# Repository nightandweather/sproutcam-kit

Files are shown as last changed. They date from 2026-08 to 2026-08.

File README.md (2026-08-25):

# SproutCam Build Kit

카메라와 환경 센서로 고가 식물의 발근·순화·성장을 기록하는 스마트 재배 캐비닛 설계 프로젝트입니다.

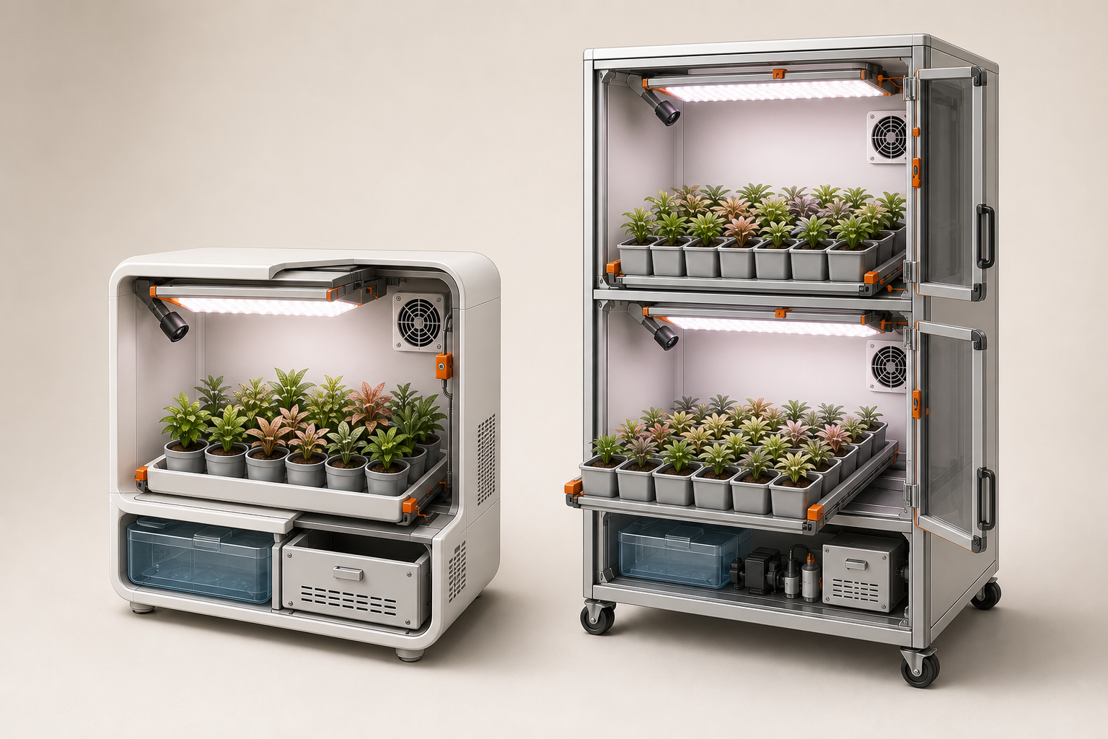
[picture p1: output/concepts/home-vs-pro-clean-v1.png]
HOME 12 and PRO 48 concept


> [!IMPORTANT]
> 이 저장소는 공개 열람이 가능한 설계 프로젝트이지만 오픈소스 또는 오픈 하드웨어로 사용 허가된 저장소가 아닙니다. 별도 서면 허가 없이 설계·코드·문서·이미지를 제품 생산, 판매, 유료 설치, OEM/ODM, 재배포 또는 상업적 파생 제품에 사용할 수 없습니다. 자세한 내용은 [권리 및 상업적 이용 정책](RIGHTS.md)을 확인하십시오.

## 제품군

| 모델 | 구조 | 대상 | 소매 시제품 예산 | 50대 목표 제조원가 |
|---|---:|---|---:|---:|
| HOME 12 | 1구역·12포트 | 개인 수집가·삽수 판매자 | 568,430원 | 399,100원/대 |
| PRO 48 | 2구역·48포트 | 소형 농가·판매점·육묘 작업자 | 1,419,240원 | 971,000원/대 |

금액은 2026-08-25 국내 소매 구매 기준 설계 예산입니다. 공구, 앱·서버 개발, 인증, 금형, 창고와 판매 수수료는 제외합니다.

## 바로 보기

- [HOME 12 + PRO 48 제품 제작서 PDF](output/pdf/SproutCam-HOME12-PRO48-제품제작서-v0.1.pdf)
- [HOME 12 BOM](docs/HOME12_BOM.csv)
- [PRO 48 BOM](docs/PRO48_BOM.csv)
- [프로파일·패널 절단표](docs/HOME_PRO_CUTLIST.csv)
- [이 사업을 계속할지 판단하는 현실 점검](docs/BUSINESS_REALITY_CHECK.md)
- [HOME/PRO 고정구 CAD 생성기](cad/generate_home_pro.py)
- [HOME/PRO STL](output/stl/home-pro/)
- [HOME/PRO STEP](output/step/home-pro/)

## 설계 원칙

- 광원은 위, 식물은 아래에 둡니다.
- 병 전파를 줄이기 위해 공용 순환수조 대신 개별 화분과 탈착식 방수 트레이를 사용합니다.
- 캐비닛 전체는 출력하지 않습니다. 구조는 알루미늄 프로파일·판재·시판 트레이로 만들고, LED 클립·카메라 브래킷·센서 가드·케이블 클립·트레이 스토퍼만 PETG로 출력합니다.
- 제품은 광주기, 습도, 환기, 촬영과 누수 감지를 담당합니다. 냉난방은 실내 설치 환경이 담당합니다.
- 220V 변환은 KC 인증 외장 어댑터에서 끝내고 본체 내부에는 24V/5V DC만 넣습니다.

## HOME 12

- 외형: 560 W x 400 D x 600 H mm
- 2020 알루미늄 프로파일
- 4 x 3 배열의 12개 개별 화분
- 24V 30 W 풀스펙트럼 LED 바 2개
- XIAO ESP32-S3 Sense 카메라 1개
- SHT40, 팬 2개, 분리형 초음파 가습수조, 누수 센서
- KC 24V 5A 120 W 외장 어댑터

## PRO 48

- 외형: 680 W x 560 D x 1700 H mm
- 3030 알루미늄 프로파일과 브레이크 캐스터
- 24포트 독립 구역 2개
- 구역당 24V 40 W 풀스펙트럼 LED 바 2개
- 구역당 카메라·센서·팬·가습수조·제어기 1세트
- 구역당 KC 24V 150 W 이상 외장 어댑터
- 사용 중 상단을 벽체 또는 고정 구조물에 연결

## 제작 순서

1. BOM에서 트레이, 화분, LED와 프로파일을 먼저 구매합니다.
2. 실물 외경과 LED 단면을 측정합니다.
3. 절단표로 프로파일과 패널을 주문합니다.
4. `cad/generate_home_pro.py`의 치수를 확인하고 STL/STEP을 생성합니다.
5. 케이블 클립 한 개를 시험 출력해 프로파일 공차를 확인합니다.
6. 제작서 순서대로 건식 조립합니다.
7. 전자부품을 넣기 전에 24시간 누수 시험을 합니다.
8. 배선 후 누수 차단, 저수위 차단, 4시간 열 시험과 정전 복구 시험을 수행합니다.

CadQuery 실행 예시:

```bash
python3 -m venv .venv
source .venv/bin/activate
pip install cadquery
python cad/generate_home_pro.py
```

PDF 재생성 예시:

```bash
pip install reportlab
python tools/build_home_pro_manual.py
```

## SproutCam One v0.1

저장소에는 앞서 만든 2포트 탁상형 수경재배 실험기도 함께 들어 있습니다.

- [2포트 조립설명서 PDF](output/pdf/SproutCam-One-조립설명서.pdf)
- [기존 BOM](docs/BOM.csv)
- [기존 조립 안내](docs/ASSEMBLY.md)
- [기존 배선 안내](docs/WIRING.md)
- [기존 펌웨어](firmware/)

## 안전 및 판매 전 검토

이 저장소는 개발 시제품용입니다. 실제 판매 전에는 전파·전기·재료·내구·표시 의무에 대해 시험기관과 별도 검토가 필요합니다. 누전차단기가 있는 콘센트를 사용하고, 젖은 구역과 전자함을 분리하며, PRO 48에는 전도 방지 고정을 반드시 적용하십시오.

## 사업성에 관한 입장

이 설계가 기술적으로 가능하다는 사실과 시장에서 팔린다는 사실은 다릅니다. 일반 가정의 채소 자급용 제품으로는 경제성이 약하다는 반론을 포함해, 가능한 고객과 중단 기준을 [사업성 현실 점검](docs/BUSINESS_REALITY_CHECK.md)에 기록했습니다.

## 상업적 협업

다음과 같은 유료 협업을 검토합니다.

- 앱·펌웨어·카메라 기반 생육 분석 연동
- 소규모 재배 실증과 맞춤형 시제품 개발
- 키트 제작, 제조 이관, OEM/ODM 검토
- 설계와 소프트웨어의 상업적 라이선스

상업적 이용 또는 협업 문의는 [새 이슈](https://github.com/nightandweather/sproutcam-kit/issues/new)를 통해 먼저 연락해 주십시오. 이슈는 공개되므로 예산, 계약서, 기술 비밀과 개인정보는 작성하지 마십시오.

## 프로젝트 후원

이 프로젝트의 공개 문서, 실험 기록과 후속 시제품 개발을 후원하려면 [GitHub Sponsors](https://github.com/sponsors/nightandweather)를 이용할 수 있습니다. 후원은 상업적 사용권을 부여하지 않습니다.

## 권리

Copyright © 2026 Lee Kang Houn. All rights reserved.

이 저장소에 별도 라이선스가 명시되지 않은 한 모든 권리는 저작권자에게 유보됩니다. 공개 저장소라는 사실이나 GitHub에서 포크할 수 있다는 사실만으로 제조·판매·재배포 또는 파생 저작물 작성 권한이 부여되지는 않습니다. 전체 정책은 [RIGHTS.md](RIGHTS.md)를 참조하십시오.

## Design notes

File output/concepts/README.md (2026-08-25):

# Concept images

- `home-vs-pro-clean-v1.png`: current cover and README render. Use the dimensions in the fabrication manual, BOM and cut list.
- `archive/home-vs-pro-early-annotated-v1.png`: early visual exploration. Its printed dimensions were superseded by the engineering layout and must not be used for fabrication.

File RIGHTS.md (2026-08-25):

# Rights and Commercial Use Policy

Copyright © 2026 Lee Kang Houn. All rights reserved.

## Status of this repository

This repository is publicly viewable for evaluation, discussion, education about the project, and potential collaboration. It is **source-available, not open source and not open hardware**. No open-source or open-hardware licence is granted unless a specific file or directory explicitly says otherwise.

GitHub users may view and fork the repository only to the extent provided by GitHub's Terms of Service. Public availability does not grant a licence to reproduce, modify, distribute, manufacture from, sell, rent, install for a fee, sublicense, or otherwise commercially exploit the materials in this repository.

## Rights reserved

Without prior written permission from the copyright holder, you may not:

- manufacture or commission a product from the CAD files, drawings, cut lists, BOMs, firmware, or documentation;
- sell, rent, bundle, install for a fee, or commercially deploy a product based substantially on these materials;
- use the materials for OEM, ODM, white-label, consulting, training, or other paid services;
- redistribute, mirror, repackage, sublicense, or publish modified copies of the materials;
- incorporate the materials into a commercial product or a commercially used derivative work; or
- use the SproutCam name, product names, artwork, or project identity in a way that suggests endorsement or an official product.

Ideas, facts, interfaces, third-party components, and other material that cannot be restricted by applicable law are not made exclusive merely by this notice. Third-party dependencies and referenced products remain subject to their own terms and licences.

## Commercial licences and paid collaboration

Commercial manufacturing, product integration, custom development, pilots, and licensing may be available under a separate written agreement. Start a public [commercial inquiry](https://github.com/nightandweather/sproutcam-kit/issues/new) without including confidential information. Sensitive technical, financial, or contractual details should only be exchanged after a private channel and appropriate terms have been agreed.

A donation or sponsorship does not grant manufacturing, redistribution, trademark, patent, support, warranty, or commercial-use rights.

## Contributions

Do not submit substantial code, CAD, documentation, or other copyrighted contributions unless contribution terms have been agreed in advance. Opening an issue or pull request does not transfer ownership and does not create a commercial licence.

## Future releases

Future community editions, individual files, or directories may be offered under separate licences. Any such licence applies only where it is explicitly identified and does not change the status of the rest of this repository.

## No warranty

The materials are experimental prototypes supplied for review without warranty. They have not been certified for sale, electrical safety, radio compliance, food production, plant health, structural safety, or unattended operation. The copyright holder is not offering installation, maintenance, regulatory, or safety assurance through publication of this repository.

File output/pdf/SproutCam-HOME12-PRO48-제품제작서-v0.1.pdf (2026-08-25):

SPROUTCAM PRODUCT BUILD BOOK / v0.1

# SPROUTCAM

# HOME 12 + PRO 48

### 제품 제작서 / 견적서 / 조립 검사서 v0.1

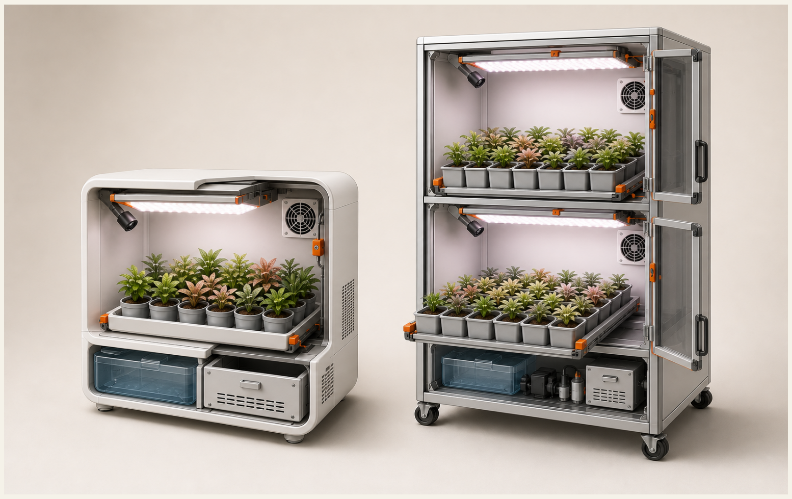
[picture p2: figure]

설계 결론 | 광원은 위, 식물은 아래입니다. 고가 식물의 병 전파를 막기 위해 공용 순환수조 대신 개별 화분과 탈착식 방수 트레이를 사용합니다.
작성 기준일 2026-08-25 | 치수 단위 mm | 금액 VAT 포함 소매 추정

# 0. 먼저 보는 결론

### 직접 한 대를 만드는 예산과 판매용 50대 생산의 제조원가는 다릅니다. 아래 금액은 현재 설계를 실제로 구매 가능한 부품으로

조립하기 위한 기준선입니다.

모델 | 소매 시제품 | 50대 목표 제조원가 | 권장 시험 판매가
HOME 12 | 568,430원 | 399,100원/대 | 799,000-899,000원
PRO 48 | 1,419,240원 | 971,000원/대 | 1,890,000-2,190,000원
원가에 포함 | 본체 구조, 패널, 트레이, 화분, LED, 카메라 제어기, 센서, 팬, 가습, 외장 전원, 소모품, 소매 배송. 50대 목표에는 조립·검사, 포장, 보증충당도 포함.
원가에 제외 | 3D 프린터와 공구, 앱·서버 개발, 금형, KC·EMC·방수 시험, 창고, 반품 물류, 판매 수수료, 마케팅, 부가세 환급 효과.

# 제품 역할 분리

제품이 제어 | 설치 공간이 담당 | 이번 버전에서 제외
광주기·광량 습도·환기 성장 촬영·기록 누수 감지 | 실내 온도 20-28 C 급배수 접근 안정적인 Wi-Fi 주기적 물 보충 | 냉난방 자동 영양액 배합 병해충 완전 진단 판매 등급 자동 판정

### 핵심 판단: HOME은 개인 수집가의 발근·순화·성장 기록 장비이고, PRO는 소형 농가나 식물 판매자의 2구역 생산 장비입니다. 단순

채소 재배기보다 고가 삽수·유묘의 생존률과 기록성을 파는 편이 가격 방어가 쉽습니다.

# 1. 시스템 구조와 안전 경계

### 판매 가능한 제품으로 발전시키려면 처음부터 물과 전원의 경계를 명확히 해야 합니다. 본체 안에는 SELV 저전압 DC만 넣고 220V

변환은 KC 인증 외장 어댑터에서 끝냅니다.

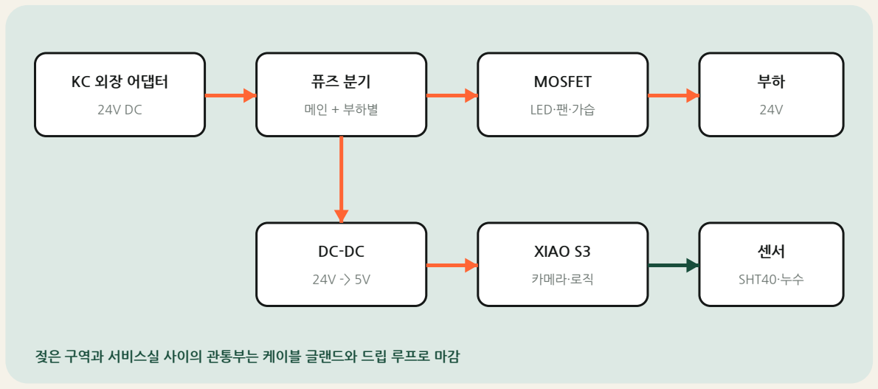
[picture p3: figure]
KC 외장 어댑터; 메인 + 부하별; MOSFET; LED·팬·가습; XIAO S3; 카메라·로직; SHT40·누수; 젖은 구역과 서비스실 사이의 관통부는 케이블 글랜드와 드립 루프로 마감

항목 | 제작 기준 | 불합격 조건
전원 | 외장 24V 어댑터, 본체 입구 퓨즈 | 본체 내부 220V 배선
물 | 트레이·가습수조 독립, 드립 루프 | 전자함 위쪽 호스 연결
전자함 | 서비스실 상단, IP54 이상 목표 | 바닥 최저점에 장착
가습 | 저수위 보호, 최대 연속 15분 | 무수 상태 발진 가능
열 | LED 알루미늄 방열판, 팬 정지 감지 | 30분 후 표면 60 C 초과
소프트웨어 | 로컬 타임아웃 우선 | 클라우드 장애 시 계속 켜짐
작업 전 | 누전차단기가 있는 콘센트를 사용하고, 빈 캐비닛 누수 시험 24시간을 통과하기 전에는 전자부품을 설치하지 않습니다.

# 2. HOME 12 기구 설계

## 외형 560 W x 400 D x 600 H

### 재배 12포트 / 4 x 3

### 식물-LED 250-330 mm

### 서비스실 높이 130 mm

### 트레이 520 x 340 x 50

### 본체 내부는 24V / 5V DC

### 권장 설치: 실내 20-28 C

재료 | 절단 치수 | 수량 | 용도
2020 프로파일 | 560 | 4 | 상·하 폭
2020 프로파일 | 400 | 4 | 상·하 깊이
2020 프로파일 | 600 | 4 | 기둥
2020 프로파일 | 520 | 4 | LED·트레이 레일
2020 프로파일 | 360 | 2 | 서비스 선반
3T 투명 PC | 560x400 / 400x600x2 / 560x600 / 520x450 | 5 | 상·좌우·후면·도어
3T ABS/ACP | 520x360 | 1 | 젖음·건조 분리판

# 배치 기준

### 트레이 바닥은 서비스실 위 148 mm, 화분 상단은 약 235 mm, LED 방열판은 520 mm에 둡니다. 키가 작은 삽수는 LED 레일을 60

mm 아래로 이동합니다. 카메라는 전면 상단 모서리에서 중앙을 향해 30도로 내려다보게 설치합니다.

# 3. HOME 12 구매 목록과 원가

구분 | 시제품 1대 | 50대 목표/대
구조 | 98,000원 | 59,000원
외장 | 106,000원 | 60,000원
재배 | 39,600원 | 20,600원
출력 | 15,000원 | 8,000원
광원 | 68,000원 | 42,000원
제어 | 34,020원 | 21,500원
센서 | 9,900원 | 6,500원
환기 | 18,000원 | 11,000원
가습 | 42,000원 | 25,000원
전원 | 35,910원 | 24,000원
안전 | 13,000원 | 7,500원
기록 | 8,000원 | 5,000원
배선 | 18,000원 | 10,000원
마감 | 18,000원 | 10,000원
물류 | 45,000원 | 0원
양산 | 0원 | 89,000원

# 상세 BOM 1/2

부품 | 규격 | 수량 | 시제품 소계
2020 알루미늄 프로파일 절단 세트 | 560x4, 400x4, 600x4, 520x4, 360x2 mm | 1 | 62,000원
브라켓·T너트·M5 볼트 | 2020용 코너브라켓 24개 포함 | 1 | 36,000원
투명 폴리카보네이트 패널 | 3T 재단 5장 | 1 | 82,000원
도어 하드웨어·실리콘 씰 | 힌지 2·래치 2·손잡이 1 | 1 | 24,000원
탈착식 방수 트레이 | 520x340x50 mm 또는 근사 규격 | 1 | 18,000원
개별 화분 | 상단 75-80 mm·배수형 | 12 | 21,600원
PETG 필라멘트 | 고정구 0.65 kg 예상 | 1 | 15,000원
24V 풀스펙트럼 LED 바 | 30 W·길이 500 mm·방열판 포함 | 2 | 68,000원
XIAO ESP32-S3 Sense | 카메라 포함 | 1 | 25,520원
SHT40 온습도 보드 | I2C·3.3 V | 1 | 9,900원
80 mm 저소음 팬 | 24 V 또는 12 V | 2 | 18,000원
24V 초음파 미스트 모듈 | 저수위 보호형 권장 | 1 | 24,000원

# 3. HOME 12 구매 목록과 원가

# 상세 BOM 2/2

부품 | 규격 | 수량 | 시제품 소계
가습수 탱크·덕트·체크밸브 | 2 L 분리형 | 1 | 18,000원
4채널 MOSFET 보드 | 3.3 V 로직 호환 | 1 | 8,500원
DC-DC 벅 컨버터 | 24 V to 5 V 3 A | 1 | 6,000원
KC 24V 5A 외장 어댑터 | 120 W·접지형 | 1 | 29,910원
인라인 퓨즈·분기 단자 | 메인 5 A·부하별 1-3 A | 1 | 7,000원
누수 센서 | 접점식 또는 로프형 | 1 | 6,000원
microSD 카드 | 32 GB·고내구 권장 | 1 | 8,000원
케이블·JST·글랜드·열수축튜브 | 24/5 V 하네스 1식 | 1 | 18,000원
볼트·방수테이프·실란트 | 1식 | 1 | 18,000원
개별 배송비 합계 | 판매처 통합 전 소매 구매 | 1 | 45,000원
포장재 | 이중 골판지·완충재·설명서 | 1 | 0원
조립·검사 인건비 | 약 2.0시간 | 1 | 0원
초기불량·보증 충당 | 목표 제조원가의 약 5% | 1 | 0원
구매 순서 | 먼저 프로파일·트레이·화분·LED 실물 치수를 확정한 뒤 패널 재단과 3D 출력을 주문합니다. 트레이와 LED를 나중에 바꾸면 고정구를 다시 출력하게 됩니다.

# 4. HOME 12 조립 순서

### 01 하부 사각 프레임과 4개 기둥을 손조임으로 조립합니다. 대각선 길이 차가 2 mm 이내인지 확인한 뒤

체결합니다.

02 높이 130 mm에 서비스 선반 레일을 설치하고 ABS/ACP 분리판 둘레를 중성 실리콘으로 밀봉합니다.

03 트레이 레일과 3D 출력 코너 스토퍼 4개를 설치합니다. 트레이는 앞쪽으로 완전히 빠져야 합니다.

04 상·후·측면 PC 패널을 장착하고 전면 도어 간극 3 mm를 확보합니다. 환기 팬은 후면 상단 배기로 둡니다.

### 05 LED 두 줄을 알루미늄 레일과 출력 클립으로 고정합니다. 방열판과 PC 상판 사이 간격은 20 mm

이상입니다.

### 06 카메라 브래킷, SHT40 가드, 케이블 클립을 장착합니다. 센서는 미스트 직분사와 LED 열원에서 120 mm

이상 떨어뜨립니다.

### 07 가습수조와 덕트를 서비스실 왼쪽, 전자함을 오른쪽에 배치합니다. 모든 호스 연결부는 전자함보다 낮게

둡니다.

### 08 24시간 누수 시험 후 배선하고 5V 레일, 팬 방향, 저수위 차단, 누수 경보, 카메라 화각을 순서대로

검사합니다.

# 5. HOME 12 배선과 전력

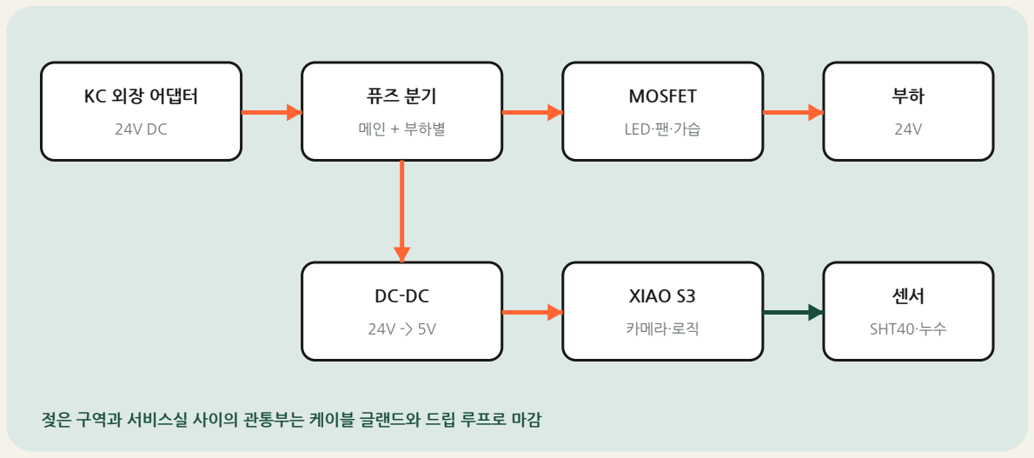
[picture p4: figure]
KC 외장 어댑터; 메인 + 부하별; MOSFET; LED·팬·가습; XIAO S3; 카메라·로직; SHT40·누수; 젖은 구역과 서비스실 사이의 관통부는 케이블 글랜드와 드립 루프로 마감

부하 | 정격 | 예상 최대 | 퓨즈
LED 2개 | 24V | 60 W / 2.5 A | 3 A
미스트 | 24V | 24 W / 1.0 A | 1.5 A
팬 2개 | 24V 또는 12V | 6 W / 0.25 A | 1 A
제어·카메라 | 5V | 5 W / 1.0 A | 벅 입력 1 A
합계 | 24V | 약 95 W / 4.0 A | 메인 5 A
기능 | 연결 | 제어 규칙
SHT40 | I2C SDA/SCL | 30초 평균, 결로 방지
LED | MOSFET CH1 | 기본 12시간, PWM 선택
배기 팬 | MOSFET CH2 | 습도 상한 또는 주기 환기
미스트 | MOSFET CH3 | 최대 15분, 5분 휴지
누수 | 디지털 입력 | 감지 즉시 모든 부하 OFF

HOME 피크 부하는 95 W이므로 24V 5A 120 W 어댑터에 약 20% 여유가 남습니다. LED나 미스트 모듈을 상향하면 어댑터와 메인 퓨즈를 다시 계산해야 합니다.

# 6. PRO 48 기구 설계

## 외형 680 W x 560 D x 1700 H

### 2개 독립 구역 x 24포트

### 구역별 LED 80 W

### 구역별 카메라·센서·가습

### 트레이 610 x 470 x 40

### 서비스실 높이 280 mm

### 구역당 24V 150 W 어댑터

### 브레이크 캐스터 4개

재료 | 절단 치수 | 수량 | 용도
3030 프로파일 | 1700 | 4 | 기둥
3030 프로파일 | 680 | 8 | 상·하·구역 폭
3030 프로파일 | 560 | 12 | 상·하·구역 깊이
4T 투명 PC | 680x560 / 560x1700x2 / 680x1700 | 4 | 상·좌우·후면
4T 투명 PC | 640x600x2 / 640x250 | 3 | 구역·서비스 도어
4T ABS/ACP | 620x500 | 3 | 구역 바닥·분리판
독립 2구역 | ZONE A와 B는 어댑터, 제어기, 센서, 팬, 가습수조를 따로 둡니다. 한 구역 고장이나 병 발생이 다른 구역으로 번지는 것을 줄이고 서로 다른 순화 레시피를 운전할 수 있습니다.

# 7. PRO 48 구매 목록과 원가

구분 | 시제품 1대 | 50대 목표/대
구조 | 295,000원 | 175,000원
외장 | 252,000원 | 143,000원
재배 | 135,600원 | 70,000원
출력 | 28,000원 | 15,000원
광원 | 176,000원 | 108,000원
제어 | 68,040원 | 43,000원
센서 | 19,800원 | 13,000원
환기 | 48,000원 | 30,000원
가습 | 102,000원 | 60,000원
전원 | 91,800원 | 62,000원
안전 | 26,000원 | 15,000원
기록 | 16,000원 | 10,000원
배선 | 35,000원 | 21,000원
마감 | 36,000원 | 21,000원
물류 | 90,000원 | 0원
양산 | 0원 | 185,000원

# 상세 BOM 1/2

부품 | 규격 | 수량 | 시제품 소계
3030 알루미늄 프로파일 절단 세트 | 1700x4, 680x8, 560x12 mm | 1 | 210,000원
브라켓·T너트·M6 볼트 | 3030용 보강 브라켓 48개 포함 | 1 | 85,000원
투명 폴리카보네이트 패널 | 4T 재단·도어 포함 | 1 | 210,000원
도어 하드웨어·자석 씰 | 힌지 6·래치 6·손잡이 3 | 1 | 42,000원
탈착식 방수 트레이 | 610x470x40 mm | 2 | 78,000원
개별 화분 | 상단 75-80 mm·배수형 | 48 | 57,600원
PETG 필라멘트 | 고정구 1.4 kg 예상 | 1 | 28,000원
24V 풀스펙트럼 LED 바 | 40 W·길이 600 mm·방열판 포함 | 4 | 176,000원
XIAO ESP32-S3 Sense | 구역별 카메라 포함 | 2 | 51,040원
SHT40 온습도 보드 | I2C·3.3 V | 2 | 19,800원
120 mm 저소음 팬 | 24 V 또는 12 V | 4 | 48,000원
24V 초음파 미스트 모듈 | 구역별·저수위 보호형 | 2 | 56,000원

# 7. PRO 48 구매 목록과 원가

# 상세 BOM 2/2

부품 | 규격 | 수량 | 시제품 소계
가습수 탱크·덕트·체크밸브 | 구역별 3 L 분리형 | 2 | 46,000원
4채널 MOSFET 보드 | 3.3 V 로직 호환 | 2 | 17,000원
DC-DC 벅 컨버터 | 24 V to 5 V 3 A | 2 | 12,000원
KC 24V 6.25A 이상 외장 어댑터 | 구역별 150 W 이상·접지형 | 2 | 79,800원
인라인 퓨즈·분기 단자 | 구역별 메인 5 A·부하별 1-3 A | 2 | 14,000원
누수 센서 | 구역별 접점식 또는 로프형 | 2 | 12,000원
microSD 카드 | 32 GB·고내구 권장 | 2 | 16,000원
케이블·JST·글랜드·열수축튜브 | 2구역 하네스 1식 | 1 | 35,000원
캐스터·볼트·실란트·받침판 | 브레이크 캐스터 4개 포함 | 1 | 36,000원
개별 배송·화물비 합계 | 판매처 통합 전 소매 구매 | 1 | 90,000원
포장재 | 이중 골판지·모서리 보강·설명서 | 1 | 0원
조립·검사 인건비 | 약 4.0시간 | 1 | 0원
초기불량·보증 충당 | 목표 제조원가의 약 5% | 1 | 0원

### 큰 원가 3개

### 외장·프레임 약 54.7만원, 광원 17.6만원, 배송·조립 준비 약 9만원이 시제품 가격을 끌어올립니다. 실제 양산에서는 패널 네스팅과 프로파일 일괄 절단이 가장 먼저 절감할

부분입니다.

# 8. PRO 48 조립 순서

### 01 캐스터가 달린 하부 3030 프레임을 조립하고 수평계를 사용합니다. 두 대각선 차이는 3 mm 이내로

맞춥니다.

02 기둥 4개와 상부 프레임을 세운 뒤 벽 고정용 전도 방지 스트랩 위치를 확보합니다.

03 높이 280, 930, 1610 mm에 구역 레일을 설치하고 ABS/ACP 분리판 둘레를 실링합니다.

### 04 각 구역 트레이 레일과 스토퍼를 설치합니다. 24개 화분을 넣은 상태에서도 한 손으로 트레이가 빠져야

합니다.

05 구역당 LED 2줄, 배기 팬 2개, 카메라 1개, SHT40 1개를 설치합니다. 두 구역의 하네스 색을 다르게 합니다.

### 06 서비스실을 좌측 가습수조 A/B, 중앙 전원 입구, 우측 전자함 A/B로 구획합니다. 물통은 별도 누수받이에

둡니다.

07 패널과 도어를 설치하고 각 구역의 문을 닫았을 때 2-5 mm 흡기 간극을 남깁니다.

08 구역별 24시간 누수 시험, 4시간 열 시험, 정전 복구, 네트워크 단절, 누수 센서 강제 작동 시험을 합니다.

# 9. PRO 48 배선과 전력

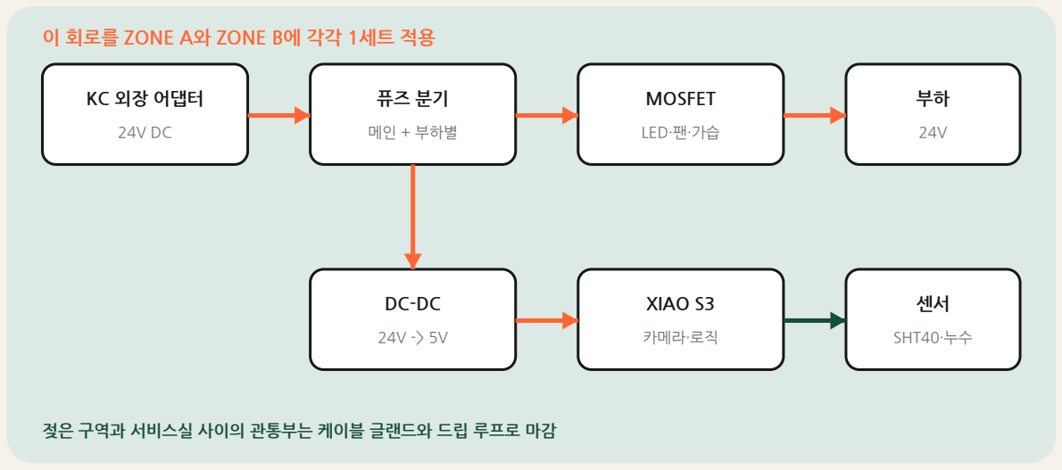
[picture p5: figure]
KC 외장 어댑터; 메인 + 부하별; MOSFET; LED·팬·가습; XIAO S3; 카메라·로직; SHT40·누수; 젖은 구역과 서비스실 사이의 관통부는 케이블 글랜드와 드립 루프로 마감; 이 회로를 ZONE A와 ZONE B에 각각 1세트 적용

구역당 부하 | 정격 | 예상 최대 | 퓨즈
LED 2개 | 24V | 80 W / 3.33 A | 4 A
미스트 | 24V | 24 W / 1.0 A | 1.5 A
팬 2개 | 24V 또는 12V | 10 W / 0.42 A | 1 A
제어·카메라 | 5V | 5 W / 1.0 A | 벅 입력 1 A
합계 | 24V | 약 119 W / 5.0 A | 메인 6.3 A

### 구역마다 24V 150 W 이상 외장 어댑터를 사용합니다. 120 W 어댑터는 정격과 피크가 너무 가까워 제외했습니다. 두 구역의 DC

음극을 합치지 않아도 되며, 통신은 Wi-Fi로 묶는 편이 고장 격리에 유리합니다.

전도 방지 | PRO 48은 높이 1700 mm입니다. 브레이크 캐스터만으로는 부족하므로 사용 중에는 상단을 벽체 또는 고정 구조물에 스트랩으로 연결하십시오.

# 10. 3D 출력 고정구

### 캐비닛 전체를 출력하지 않습니다. 크고 물을 받는 부품은 프로파일·판재·시판 트레이로 만들고, 치수 적응이 필요한 작은 고정구만

PETG로 출력합니다.

파일 | HOME | PRO | 권장 수량 | 역할
led_clip_2020 / 3030 | 2020 | 3030 | 8 / 16 | LED 레일 고정
camera_bracket_*_30deg | 2020 | 3030 | 1 / 2 | 카메라 30도 설치
sht40_sensor_guard | 공용 | 공용 | 1 / 2 | 센서 비말 보호
cable_clip_2020 / 3030 | 2020 | 3030 | 12 / 24 | 하네스 정리
tray_corner_2020 / 3030 | 2020 | 3030 | 4 / 8 | 트레이 위치 반복
설정 | 권장값 | 이유
재료 | PETG | 습기·열에 PLA보다 안정
노즐/레이어 | 0.4 / 0.20 mm | 치수와 시간 균형
벽/상하단 | 4줄 / 5레이어 | 클립 파손 억제
인필 | 30% gyroid | 충격 방향 분산
공차 | 프로파일 +0.8 mm | 프린터 편차 흡수
볼트 | M4 관통 + T너트 | 스냅만으로 하중 지지 금지

STL은 output/stl/home-pro, 수정 가능한 STEP은 output/step/home-pro에 생성됩니다. 첫 출력은 케이블 클립 1개로 프로파일 맞춤을 확인한 후 진행합니다.

# 11. 완성품 검사와 최초 가동

시험 | 방법 | 합격 기준
프레임 | 대각선·수평·도어 반복 | 흔들림 없음, 간극 일정
누수 | 트레이·가습수조 만수 24시간 | 바닥·관통부 물방울 0
절연 경계 | 어댑터 분리 후 내부 확인 | 220V 부품 0개
5V 레일 | 카메라 스트리밍 중 측정 | 4.85-5.15V
열 | 모든 부하 4시간 | LED 60 C 이하, 커넥터 변색 0
누수 차단 | 센서에 물 3 ml | 5초 안에 모든 부하 OFF
저수위 | 가습수조 비우기 | 미스트 기동 거부
통신 장애 | Wi-Fi 30분 차단 | 예약·안전 타임아웃 유지
정전 복구 | 전원 5회 반복 | 미스트 OFF로 안전 부팅
카메라 | 빈칸 없이 전체 포트 확인 | HOME 12 / PRO 각 24포트 식별

# 가동 레시피 초안

단계 | 기간 | 습도 | 광주기 | 환기
발근 | 1-7일 | 85-92% | 12h / 약광 | 10분마다 1분
순화 | 8-14일 | 하루 3%p 감소 | 12-14h | 5분마다 1분
성장 | 15일 이후 | 60-75% | 14h | 습도 상한 연동

식물 종과 기질에 따라 레시피 검증이 필요합니다. 고습 환경은 곰팡이 위험을 키우므로 상대습도만이 아니라 잎 표면 결로와 공기 흐름을 함께 관찰하십시오.

# 12. 원가를 판매가로 바꾸는 법

항목 | HOME 12 | PRO 48
시제품 BOM | 568,430원 | 1,419,240원
50대 목표 제조원가 | 399,100원 | 971,000원
시험 판매가 | 799,000-899,000원 | 1,890,000-2,190,000원
원가율 | 44-50% | 44-51%
예상 월 전력 | 약 30-45 kWh | 약 80-120 kWh
주요 고객 | 고가 관엽 수집가·삽수 판매자 | 소형 농가·판매점·육묘 작업자

# 사업성 검증 순서

1 | HOME 12 한 대를 먼저 만들고 30일 순화 로그를 공개합니다.
2 | 고가 식물 12개 중 생존률, 작업시간, 사진 기록 가치를 측정합니다.
3 | 예약금 10만원을 받는 유료 선주문 10건이 생기기 전에는 PRO 금형을 만들지 않습니다.
4 | 첫 10대는 프로파일 조립품으로 판매해 고장 데이터를 모읍니다.
5 | 50대 주문이 보이면 패널 네스팅, 하네스 외주, 판금 서비스실부터 양산화합니다.

### 돈이 되는 조건

### 기계 자체보다 '고가 삽수 12개를 한 번에 순화하면서 실패 원인을 사진과 환경 로그로 남긴다'는 결과를 팔아야 합니다. 월 구독은 원격 알림, 타임랩스 보관, 재배 레시피 공유가

실제로 반복 사용될 때만 붙입니다.

# 13. 가격 근거와 제작 전 확인

### 가격은 2026-08-25 국내 소매 구매를 가정한 예산입니다. 판매처·절단비·배송지에 따라 달라질 수 있으며, 특정 판매자의 공식 견적이

아닌 시장가 기반 설계 예산입니다.

항목 | 확인값 | 근거
XIAO ESP32-S3 Sense | VAT 포함 25,520원 | 디바이스마트 상품 페이지
24V 5A 어댑터 | 약 29,910원부터 | 다나와 24V 5A 검색 결과
2020 프로파일 | 200-800 mm 소매 비교가 존재 | 다나와 2020 프로파일 비교
나머지 부품 | 샘플 구매 예산 | 국내 쇼핑몰 1-3개 견적 후 확정

# 원문 링크

XIAO: https://www.devicemart.co.kr/goods/view?no=14991199

24V 5A 어댑터: https://search.danawa.com/mobile/dsearch.php?keyword=24v+5a+adapter

2020 프로파일: https://prod.danawa.com/info/?pcode=20334098

제작 전 실측 | 확인
구매 트레이 외경과 레일 간격 | □
화분 상단 외경과 4x3 / 6x4 피치 | □
LED 실제 길이·폭·발열·입력전압 | □
어댑터 KC 인증번호와 출력 커넥터 | □
팬 방향·전압과 최대 전류 | □
미스트 모듈 저수위 보호 동작 | □
패널 도어 간극과 힌지 홀 위치 | □
벽체 전도 방지 고정점(PRO) | □

본 문서는 개발 시제품 제작서입니다. 실제 판매 전에는 전파·전기·재료·내구·표시 의무에 대해 시험기관과 별도로 검토해야 합니다.

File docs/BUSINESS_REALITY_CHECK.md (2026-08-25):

# SproutCam 사업성 현실 점검

작성일: 2026-08-25

## 현재 결론

**일반 가정용 스마트팜으로는 사업성이 약하다. 고가 삽수·유묘를 반복 취급하는 판매자와 수집가를 위한 소형 순화 장비라면 제한적으로 검증할 가치가 있다.**

이 문서는 제품을 정당화하기 위한 자료가 아니다. 설계를 실제 제품으로 만들기 전에 왜 실패할 수 있는지 기록하고, 중단할 조건을 미리 정하기 위한 문서다.

## 대중제품이 되기 어려운 이유

1. **채소 가격을 이기기 어렵다.** 기계, 전기, 씨앗, 영양제, 청소와 실패 비용을 합치면 마트에서 채소를 사는 것보다 비싸다.
2. **자급자족 장비가 아니다.** HOME 12나 PRO 48의 재배 면적으로 가정의 식량 수요를 감당할 수 없다.
3. **관리가 사라지지 않는다.** 물 보충, 세척, 솎기, 곰팡이와 해충 관리는 자동화 이후에도 남는다.
4. **집 안 공간을 오래 점유한다.** 작은 수확량에 비해 캐비닛의 부피와 소음, 빛 공해가 크다.
5. **대기업의 존재가 시장성을 증명하지 않는다.** LG 틔운 미니는 2022년 사전판매 1,000대가 6일 만에 판매됐지만, 이후 전체 틔운 시리즈의 누적 판매량은 공개되지 않았다. 공개된 확실한 초기 판매 숫자와 지속적인 대량 수요는 구분해야 한다.

참고:

- LG 공식 사전판매 자료: https://www.lg.co.kr/media/release/24551
- 현재 LG 틔운 제품군: https://www.lge.co.kr/category/lg-tiiun
- 2023년 틔운 키트 확장 자료: https://www.lg.co.kr/media/release/27049

## 구매 이유가 성립할 수 있는 고객

| 고객 | 구매 이유 | 위험 |
|---|---|---|
| 희귀 관엽 수집가 | 비싼 삽수의 발근·순화 실패 감소 | 고객 수가 적고 가격 민감도가 불명확 |
| 삽수·유묘 개인 판매자 | 반복 작업 표준화와 성장 기록 | 판매 규모가 작으면 장비 회수 불가 |
| 소형 육묘 사업자 | 두 구역의 독립 레시피와 이력 관리 | 기존 온실 설비가 더 저렴할 수 있음 |
| 교육·전시 공간 | 관찰, 타임랩스, 체험 콘텐츠 | 일회성 예산에 의존 |

일반 소비자에게 `집에서 채소를 키우는 가전`으로 판매하지 않는다. 제품이 보호하는 식물의 가치가 장비 가격보다 충분히 높아야 한다.

## 경제성이 생기는 경계

PRO 48의 시험 판매가를 189만-219만원으로 가정한다.

### 경제성이 약한 사례

- 48칸 모두 사용
- 식물 한 개의 순이익 2만원
- 한 사이클 총 잠재 순이익 96만원
- 장비가 생존률을 20%p 높여도 추가 이익은 약 19.2만원

여러 사이클과 작업시간 절감까지 고려해야 장비를 회수할 수 있다. 이 고객에게는 판매가 어렵다.

### 경제성이 가능한 사례

- 48칸 모두 사용
- 식물 한 개의 순이익 10만원
- 생존률이 70%에서 90%로 개선
- 한 사이클 추가 이익 약 96만원

이 경우에는 2-3회 사이클 안에 장비 가격을 회수할 가능성이 생긴다. 따라서 핵심 변수는 재배 수량보다 **식물 한 개의 이익과 실제 생존률 개선 폭**이다.

## 제품명과 포지셔닝 수정안

- `HOME 12` -> `PROP 12`: 개인용 가전보다 12포트 발근·순화 장비
- `PRO 48` -> `NURSERY 48`: 2구역 48포트 소형 육묘 장비

핵심 문구는 `식물을 대신 키워준다`가 아니라 다음에 가깝다.

> 고가 삽수를 한 번에 순화하고, 실패 원인을 사진과 환경 로그로 남기는 장비.

## 제작 전에 실행할 검증

1. 현재 렌더, 제작서와 예상 가격으로 공개 제품 페이지를 만든다.
2. PROP 12는 79만-89만원, NURSERY 48은 189만-219만원을 숨기지 않고 표시한다.
3. 단순 이메일 수집이 아니라 10만원의 환불 가능한 예약금을 받는 조건을 제시한다.
4. 유료 예약 10건이 모이기 전에는 PRO 외장 금형이나 대량 부품을 발주하지 않는다.
5. 예약 고객에게 약속할 수 있는 첫 제품은 프로파일 조립식 소량 생산품으로 제한한다.
6. 30일 순화 실험에서 생존률, 작업시간, 전력, 결로, 곰팡이와 센서 오류를 공개한다.

## 중단 기준

다음 중 하나라도 충족되면 소비자 완제품 사업을 중단하거나 설계 공개 프로젝트로 남긴다.

- 목표 가격을 공개한 뒤 60일 안에 유료 예약 10건을 확보하지 못함
- 30일 시험에서 대조군 대비 생존률 개선이 10%p 미만
- HOME 제조원가가 40만원 아래로 내려가지 않음
- PRO 제조원가가 100만원 아래로 내려가지 않음
- 청소와 물 관리 시간이 주당 30분 이상 필요함
- 결로·곰팡이·누수 문제를 사용자가 분해하지 않고 해결할 수 없음
- 카메라 기록이 실제 구매 이유가 아니라 단순 구경거리로만 평가됨

## 계속할 조건

- 고객이 이미 한 개당 수만-수십만원의 식물을 반복 취급함
- 장비가 없는 현재 방식에서 손실액을 측정할 수 있음
- 순화 레시피와 사진 이력이 판매 신뢰도 또는 단가를 높임
- 소모품 강매 없이도 하드웨어와 서비스의 가격이 성립함
- 한 명의 전문 작업자가 여러 대를 관리할 수 있음

## 현재 판단의 신뢰도

- 기술적 제작 가능성: 높음
- 일반 가정용 대중시장 가능성: 낮음
- 희귀식물 수집가 시장 가능성: 낮음-중간
- 소형 판매자용 순화 장비 가능성: 중간, 유료 예약으로 확인 필요
- 프랜차이즈형 대규모 확장 가능성: 아직 판단 불가

이 프로젝트의 다음 단계는 더 정교한 렌더나 더 많은 기능이 아니다. **정해진 가격으로 실제 예약금을 내는 사람이 있는지 확인하는 것**이다.

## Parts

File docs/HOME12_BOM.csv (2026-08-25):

category | item | specification | qty | prototype_unit_krw | prototype_subtotal_krw | target_50unit_subtotal_krw | source_or_basis
구조 | 2020 알루미늄 프로파일 절단 세트 | 560x4, 400x4, 600x4, 520x4, 360x2 mm | 1 | 62000 | 62000 | 38000 | 국내 소매 절단·배송 포함 견적
구조 | 브라켓·T너트·M5 볼트 | 2020용 코너브라켓 24개 포함 | 1 | 36000 | 36000 | 21000 | 국내 소매 견적
외장 | 투명 폴리카보네이트 패널 | 3T 재단 5장 | 1 | 82000 | 82000 | 46000 | 국내 판재 재단 견적
외장 | 도어 하드웨어·실리콘 씰 | 힌지 2·래치 2·손잡이 1 | 1 | 24000 | 24000 | 14000 | 국내 소매 견적
재배 | 탈착식 방수 트레이 | 520x340x50 mm 또는 근사 규격 | 1 | 18000 | 18000 | 11000 | 시판 PP/ABS 트레이
재배 | 개별 화분 | 상단 75-80 mm·배수형 | 12 | 1800 | 21600 | 9600 | 12개 묶음 단가
출력 | PETG 필라멘트 | 고정구 0.65 kg 예상 | 1 | 15000 | 15000 | 8000 | 1 kg 롤 안분
광원 | 24V 풀스펙트럼 LED 바 | 30 W·길이 500 mm·방열판 포함 | 2 | 34000 | 68000 | 42000 | 샘플 구매 예산
제어 | XIAO ESP32-S3 Sense | 카메라 포함 | 1 | 25520 | 25520 | 17000 | https://www.devicemart.co.kr/goods/view?no=14991199
센서 | SHT40 온습도 보드 | I2C·3.3 V | 1 | 9900 | 9900 | 6500 | 국내 모듈 소매 추정
환기 | 80 mm 저소음 팬 | 24 V 또는 12 V | 2 | 9000 | 18000 | 11000 | 국내 소매 추정
가습 | 24V 초음파 미스트 모듈 | 저수위 보호형 권장 | 1 | 24000 | 24000 | 14000 | 국내 소매 추정
가습 | 가습수 탱크·덕트·체크밸브 | 2 L 분리형 | 1 | 18000 | 18000 | 11000 | 시판 용기 조합
제어 | 4채널 MOSFET 보드 | 3.3 V 로직 호환 | 1 | 8500 | 8500 | 4500 | 국내 모듈 소매 추정
전원 | DC-DC 벅 컨버터 | 24 V to 5 V 3 A | 1 | 6000 | 6000 | 3000 | 국내 모듈 소매 추정
전원 | KC 24V 5A 외장 어댑터 | 120 W·접지형 | 1 | 29910 | 29910 | 21000 | https://search.danawa.com/mobile/dsearch.php?keyword=24v+5a+adapter
안전 | 인라인 퓨즈·분기 단자 | 메인 5 A·부하별 1-3 A | 1 | 7000 | 7000 | 4000 | 국내 전장 소매 추정
안전 | 누수 센서 | 접점식 또는 로프형 | 1 | 6000 | 6000 | 3500 | 국내 모듈 소매 추정
기록 | microSD 카드 | 32 GB·고내구 권장 | 1 | 8000 | 8000 | 5000 | 국내 소매 추정
배선 | 케이블·JST·글랜드·열수축튜브 | 24/5 V 하네스 1식 | 1 | 18000 | 18000 | 10000 | 소모품 안분
마감 | 볼트·방수테이프·실란트 | 1식 | 1 | 18000 | 18000 | 10000 | 소모품 안분
물류 | 개별 배송비 합계 | 판매처 통합 전 소매 구매 | 1 | 45000 | 45000 | 0 | 구매처 수에 따른 예산
양산 | 포장재 | 이중 골판지·완충재·설명서 | 1 | 0 | 0 | 24000 | 50대 기준 목표
양산 | 조립·검사 인건비 | 약 2.0시간 | 1 | 0 | 0 | 45000 | 50대 기준 목표
양산 | 초기불량·보증 충당 | 목표 제조원가의 약 5% | 1 | 0 | 0 | 20000 | 50대 기준 목표
TOTAL | 총계 |  | 1 |  | 568430 | 399100 | 도구·인증·금형·부가세 환급·개발비 제외

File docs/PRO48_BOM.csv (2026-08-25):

category | item | specification | qty | prototype_unit_krw | prototype_subtotal_krw | target_50unit_subtotal_krw | source_or_basis
구조 | 3030 알루미늄 프로파일 절단 세트 | 1700x4, 680x8, 560x12 mm | 1 | 210000 | 210000 | 125000 | 국내 소매 절단·화물 포함 견적
구조 | 브라켓·T너트·M6 볼트 | 3030용 보강 브라켓 48개 포함 | 1 | 85000 | 85000 | 50000 | 국내 소매 견적
외장 | 투명 폴리카보네이트 패널 | 4T 재단·도어 포함 | 1 | 210000 | 210000 | 118000 | 국내 판재 재단 견적
외장 | 도어 하드웨어·자석 씰 | 힌지 6·래치 6·손잡이 3 | 1 | 42000 | 42000 | 25000 | 국내 소매 견적
재배 | 탈착식 방수 트레이 | 610x470x40 mm | 2 | 39000 | 78000 | 44000 | 주문 절곡 PP/ABS 목표
재배 | 개별 화분 | 상단 75-80 mm·배수형 | 48 | 1200 | 57600 | 26000 | 48개 묶음 단가
출력 | PETG 필라멘트 | 고정구 1.4 kg 예상 | 1 | 28000 | 28000 | 15000 | 2 kg 구매 안분
광원 | 24V 풀스펙트럼 LED 바 | 40 W·길이 600 mm·방열판 포함 | 4 | 44000 | 176000 | 108000 | 샘플 구매 예산
제어 | XIAO ESP32-S3 Sense | 구역별 카메라 포함 | 2 | 25520 | 51040 | 34000 | https://www.devicemart.co.kr/goods/view?no=14991199
센서 | SHT40 온습도 보드 | I2C·3.3 V | 2 | 9900 | 19800 | 13000 | 국내 모듈 소매 추정
환기 | 120 mm 저소음 팬 | 24 V 또는 12 V | 4 | 12000 | 48000 | 30000 | 국내 소매 추정
가습 | 24V 초음파 미스트 모듈 | 구역별·저수위 보호형 | 2 | 28000 | 56000 | 34000 | 국내 소매 추정
가습 | 가습수 탱크·덕트·체크밸브 | 구역별 3 L 분리형 | 2 | 23000 | 46000 | 26000 | 시판 용기 조합
제어 | 4채널 MOSFET 보드 | 3.3 V 로직 호환 | 2 | 8500 | 17000 | 9000 | 국내 모듈 소매 추정
전원 | DC-DC 벅 컨버터 | 24 V to 5 V 3 A | 2 | 6000 | 12000 | 6000 | 국내 모듈 소매 추정
전원 | KC 24V 6.25A 이상 외장 어댑터 | 구역별 150 W 이상·접지형 | 2 | 39900 | 79800 | 56000 | 24V 150W KC 완제품 견적 필요
안전 | 인라인 퓨즈·분기 단자 | 구역별 메인 5 A·부하별 1-3 A | 2 | 7000 | 14000 | 8000 | 국내 전장 소매 추정
안전 | 누수 센서 | 구역별 접점식 또는 로프형 | 2 | 6000 | 12000 | 7000 | 국내 모듈 소매 추정
기록 | microSD 카드 | 32 GB·고내구 권장 | 2 | 8000 | 16000 | 10000 | 국내 소매 추정
배선 | 케이블·JST·글랜드·열수축튜브 | 2구역 하네스 1식 | 1 | 35000 | 35000 | 21000 | 소모품 안분
마감 | 캐스터·볼트·실란트·받침판 | 브레이크 캐스터 4개 포함 | 1 | 36000 | 36000 | 21000 | 국내 소매 추정
물류 | 개별 배송·화물비 합계 | 판매처 통합 전 소매 구매 | 1 | 90000 | 90000 | 0 | 구매처 수에 따른 예산
양산 | 포장재 | 이중 골판지·모서리 보강·설명서 | 1 | 0 | 0 | 55000 | 50대 기준 목표
양산 | 조립·검사 인건비 | 약 4.0시간 | 1 | 0 | 0 | 85000 | 50대 기준 목표
양산 | 초기불량·보증 충당 | 목표 제조원가의 약 5% | 1 | 0 | 0 | 45000 | 50대 기준 목표
TOTAL | 총계 |  | 1 |  | 1419240 | 971000 | 도구·인증·금형·부가세 환급·개발비 제외

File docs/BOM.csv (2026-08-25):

구분 | 부품 | 규격 | 수량 | 예상단가원 | 구매후보 | 필수여부
제어 | XIAO ESP32-S3 Sense | 카메라 포함 프리솔더 권장 | 1 | 25520 | https://www.devicemart.co.kr/goods/view?no=14991199 | 필수
센서 | SHT40 온습도 모듈 | I2C 3.3V Qwiic/Grove | 1 | 9000 | https://www.devicemart.co.kr/goods/search?keyword=SHT40 | 필수
센서 | 수직 플로트 스위치 | PP 재질 NO/NC 선택형 | 1 | 4000 | https://www.devicemart.co.kr/goods/search | 필수
구동 | 5V USB 미니 수중펌프 | 80-120 L/h | 1 | 7000 | https://search.shopping.naver.com/search/all | 필수
구동 | 2채널 MOSFET 스위치 모듈 | 3.3V 로직 5-24V 부하 | 1 | 7000 | https://www.devicemart.co.kr/goods/search?keyword=MOSFET%20%EB%AA%A8%EB%93%88 | 필수
조명 | 12V 풀스펙트럼 식물 LED 바 | 길이 180-200mm 10-15W | 1 | 18000 | https://search.shopping.naver.com/search/all?query=12V%20%EC%8B%9D%EB%AC%BC%20LED%20%EB%B0%94%2015W | 필수
전원 | KC 인증 12V 3A 어댑터 | DC 5.5x2.1mm 센터 플러스 | 1 | 15000 | https://search.shopping.naver.com/search/all | 필수
전원 | DC-DC 벅 컨버터 | 12V 입력 5V 3A 출력 | 1 | 5000 | https://www.devicemart.co.kr/goods/search?keyword=12V%205V%203A%20%EB%B2%85 | 필수
배관 | 실리콘 튜브 | 내경 4mm 외경 6mm 2m | 1 | 5000 | https://search.shopping.naver.com/search/all | 필수
재배 | 네트팟 | 상단 외경 50mm | 2 | 1500 | https://search.shopping.naver.com/search/all?query=50mm%20%EB%84%A4%ED%8A%B8%ED%8C%9F | 필수
탱크 | PP 식품용기 | 외경 180x120mm 높이 90-110mm 약 1.5L | 1 | 6000 | https://search.shopping.naver.com/search/all | 필수
체결 | M4 볼트/너트 세트 | M4x12 8개 M4x20 4개 | 1 | 5000 | https://www.devicemart.co.kr/goods/search?keyword=M4%20%EB%B3%BC%ED%8A%B8 | 필수
배선 | 실리콘 전선 및 JST 커넥터 | 22AWG/26AWG 혼합 | 1 | 8000 | https://www.devicemart.co.kr/goods/search?keyword=JST%20%EC%BB%A4%EB%84%A5%ED%84%B0 | 필수
저장 | microSD 카드 | 16-32GB FAT32 | 1 | 8000 | https://search.shopping.naver.com/search/all?query=microSD%2032GB | 권장
센서 | BH1750 조도 센서 | I2C 3.3V | 1 | 4000 | https://www.devicemart.co.kr/goods/search?keyword=BH1750 | 선택

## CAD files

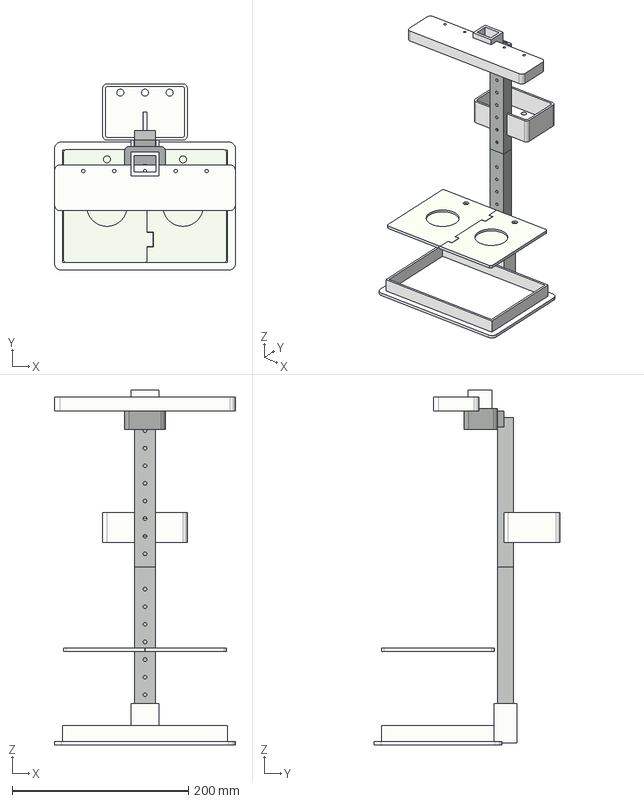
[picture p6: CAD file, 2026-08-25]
output/step/sproutcam_one_assembly.step
205.6 x 211.6 x 403.0 mm
cradle_part
lid_left_part
lid_right_part
mast_lower_part
mast_upper_part
light_part
camera_part
electronics_part

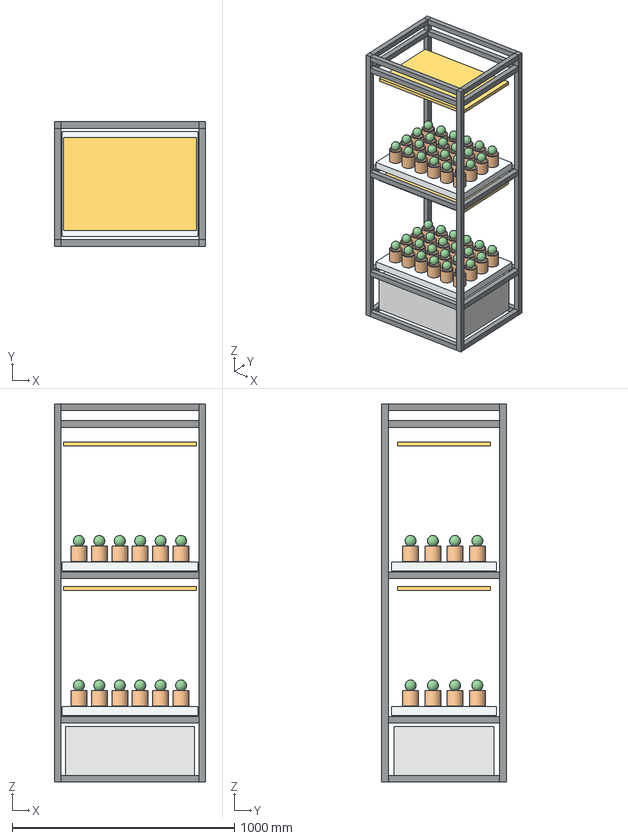
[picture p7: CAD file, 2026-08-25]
output/step/home-pro/sproutcam_pro48_reference.step
680.0 x 560.0 x 1700.0 mm
pro_post_0_0
pro_post_0_1
pro_post_1_0
pro_post_1_1
pro_w_0_0
pro_w_0_1
pro_d_0_0
pro_d_0_1
pro_w_1_0
pro_w_1_1
pro_d_1_0
pro_d_1_1
pro_w_2_0
pro_w_2_1
pro_d_2_0
pro_d_2_1
pro_w_3_0
pro_w_3_1
pro_d_3_0
pro_d_3_1
pro_w_4_0
pro_w_4_1
pro_d_4_0
pro_d_4_1
pro_tray_0
pro_led_0
pro_z0_pot_0_0
pro_z0_plant_0_0
pro_z0_pot_0_1
pro_z0_plant_0_1
pro_z0_pot_0_2
pro_z0_plant_0_2
pro_z0_pot_0_3
pro_z0_plant_0_3
pro_z0_pot_0_4
pro_z0_plant_0_4
pro_z0_pot_0_5
pro_z0_plant_0_5
pro_z0_pot_1_0
pro_z0_plant_1_0
pro_z0_pot_1_1
pro_z0_plant_1_1
pro_z0_pot_1_2
pro_z0_plant_1_2
pro_z0_pot_1_3
pro_z0_plant_1_3
pro_z0_pot_1_4
pro_z0_plant_1_4
pro_z0_pot_1_5
pro_z0_plant_1_5
pro_z0_pot_2_0
pro_z0_plant_2_0
pro_z0_pot_2_1
pro_z0_plant_2_1
pro_z0_pot_2_2
pro_z0_plant_2_2
pro_z0_pot_2_3
pro_z0_plant_2_3
pro_z0_pot_2_4
pro_z0_plant_2_4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

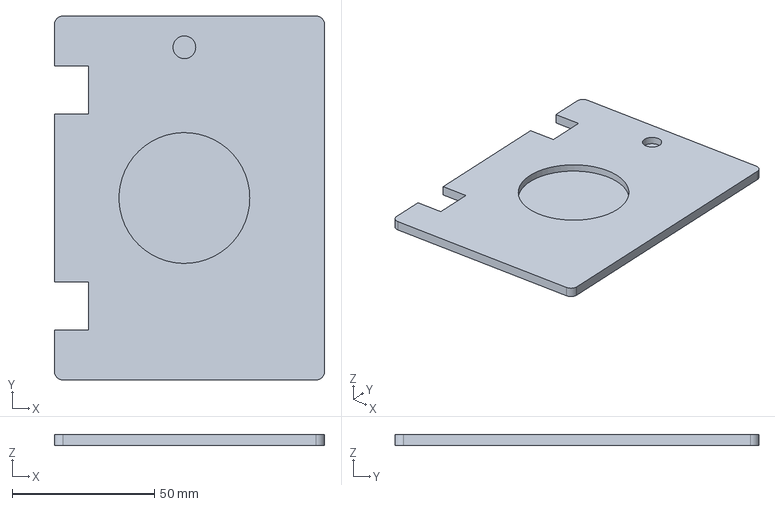
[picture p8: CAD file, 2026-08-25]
output/step/lid_right.step
95.0 x 128.0 x 4.00 mm

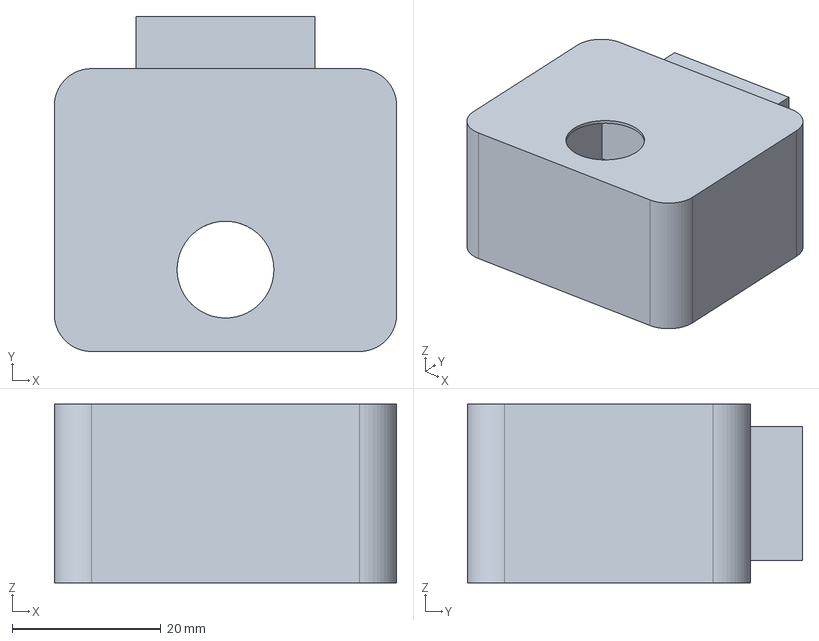
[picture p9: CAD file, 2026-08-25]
output/step/camera_pod.step
46.0 x 45.0 x 24.0 mm

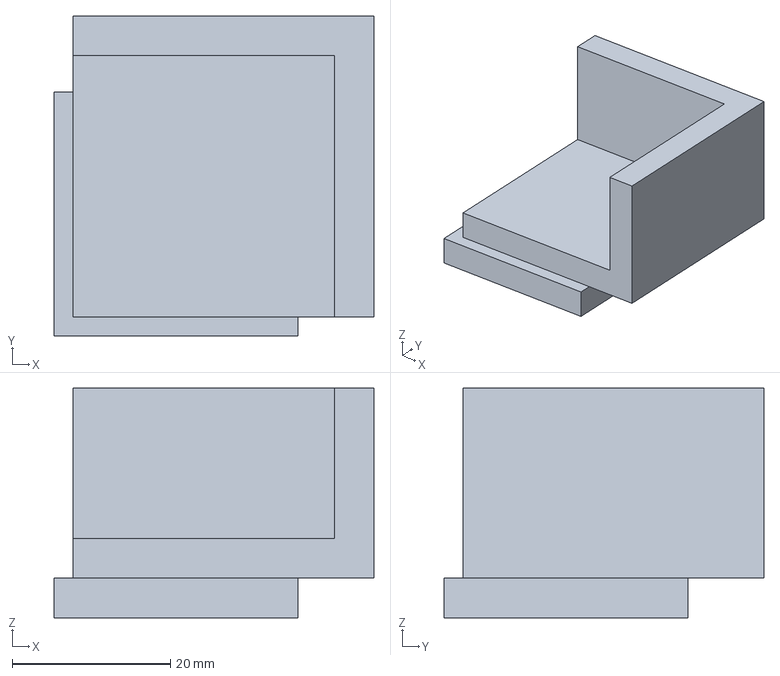
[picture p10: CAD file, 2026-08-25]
output/step/home-pro/tray_corner_3030.step
40.4 x 40.4 x 29.0 mm

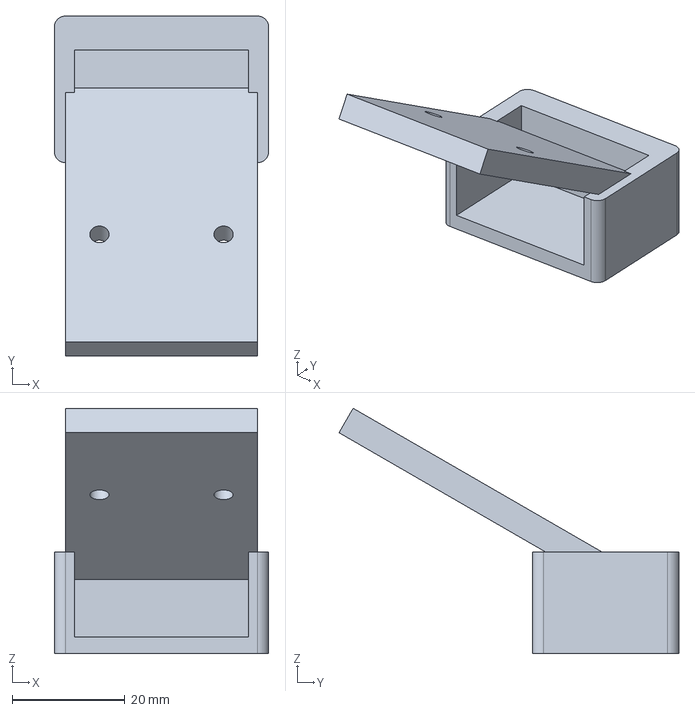
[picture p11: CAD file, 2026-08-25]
output/step/home-pro/camera_bracket_3030_30deg.step
38.0 x 60.2 x 43.5 mm

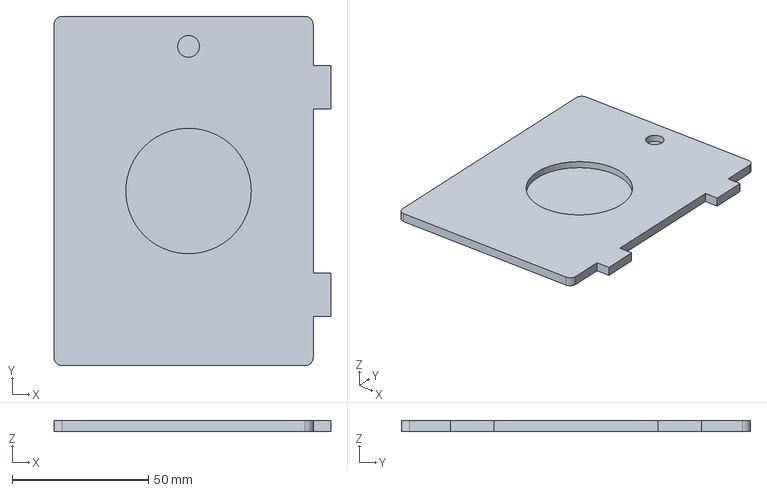
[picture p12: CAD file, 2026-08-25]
output/step/lid_left.step
101.5 x 128.0 x 4.00 mm

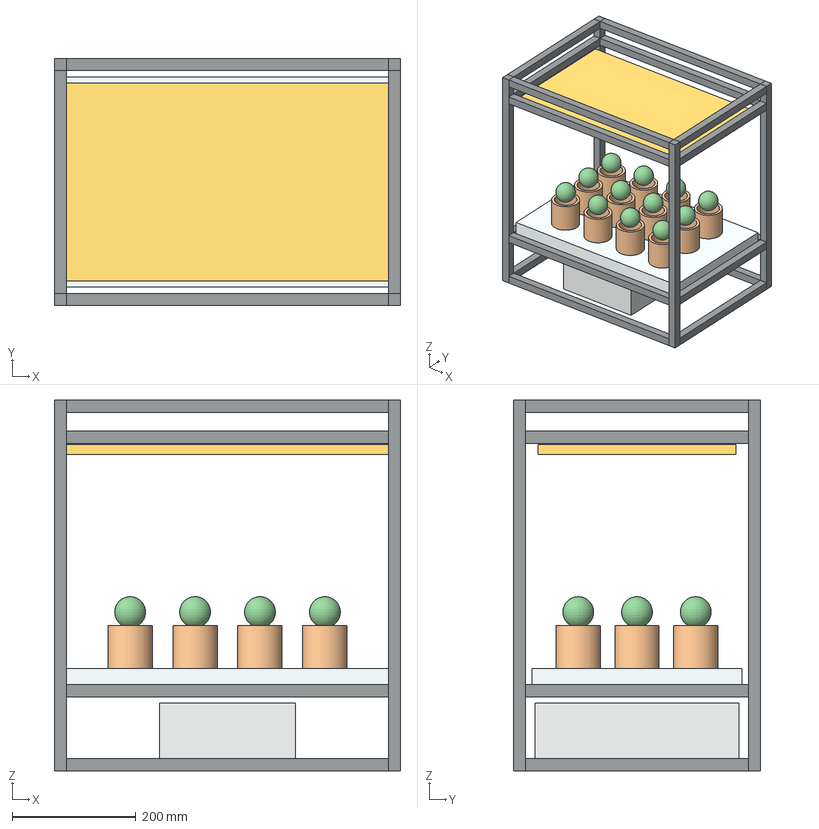
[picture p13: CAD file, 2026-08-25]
output/step/home-pro/sproutcam_home12_reference.step
560.0 x 400.0 x 600.0 mm
home_post_0_0
home_post_0_1
home_post_1_0
home_post_1_1
home_w_0_0
home_w_0_1
home_d_0_0
home_d_0_1
home_w_1_0
home_w_1_1
home_d_1_0
home_d_1_1
home_w_2_0
home_w_2_1
home_d_2_0
home_d_2_1
home_w_3_0
home_w_3_1
home_d_3_0
home_d_3_1
home_wet_tray
home_led
home_service_drawer
home_pot_0_0
home_plant_0_0
home_pot_0_1
home_plant_0_1
home_pot_0_2
home_plant_0_2
home_pot_0_3
home_plant_0_3
home_pot_1_0
home_plant_1_0
home_pot_1_1
home_plant_1_1
home_pot_1_2
home_plant_1_2
home_pot_1_3
home_plant_1_3
home_pot_2_0
home_plant_2_0
home_pot_2_1
home_plant_2_1
home_pot_2_2
home_plant_2_2
home_pot_2_3
home_plant_2_3

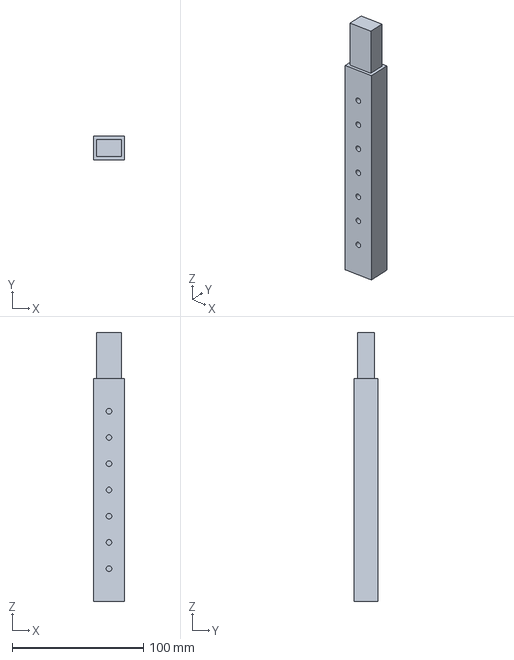
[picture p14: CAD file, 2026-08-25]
output/step/mast_lower.step
24.0 x 18.0 x 205.0 mm

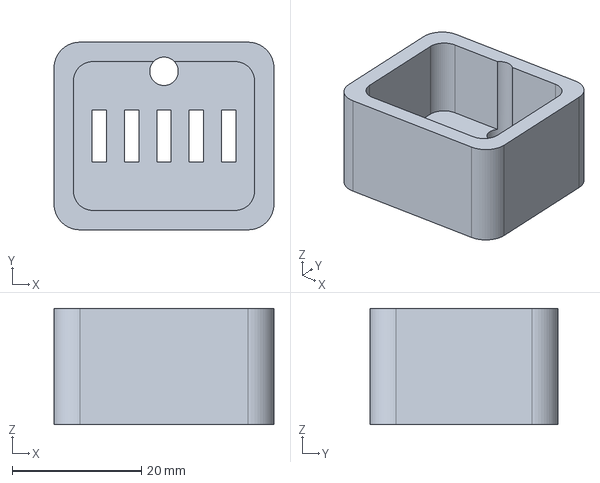
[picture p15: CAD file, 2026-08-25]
output/step/home-pro/sht40_sensor_guard.step
34.0 x 29.0 x 18.0 mm

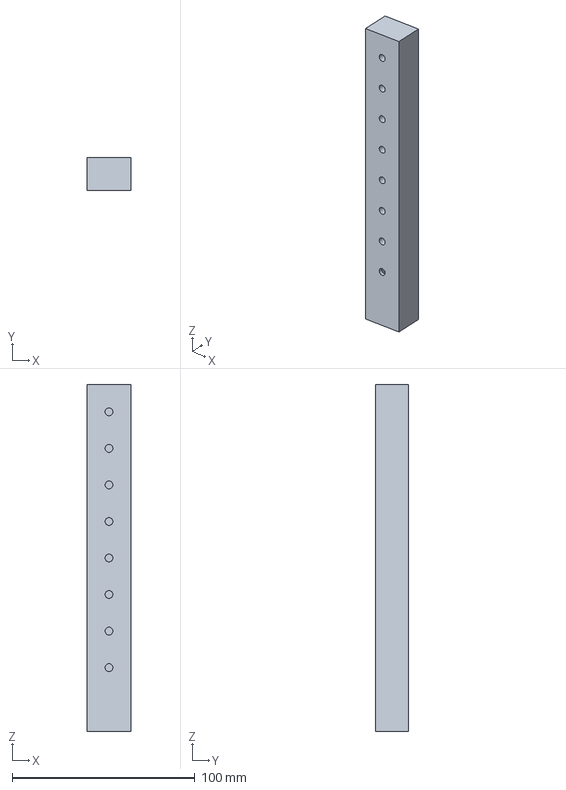
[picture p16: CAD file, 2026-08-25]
output/step/mast_upper.step
24.0 x 18.0 x 190.0 mm

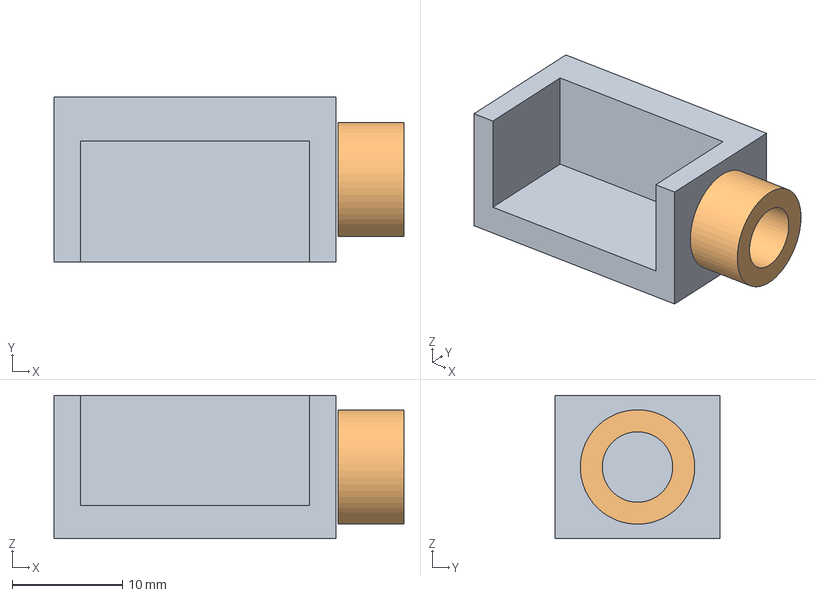
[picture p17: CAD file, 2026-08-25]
output/step/home-pro/cable_clip_2020.step
31.8 x 15.0 x 13.0 mm

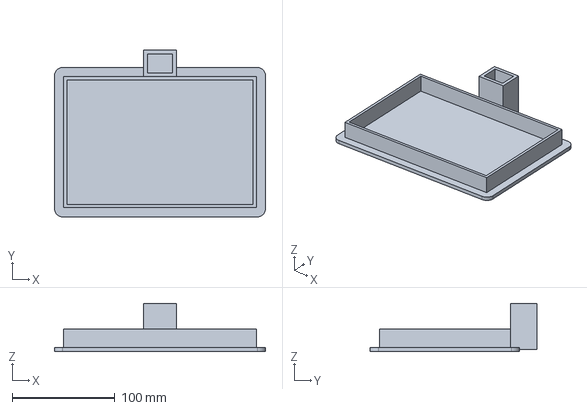
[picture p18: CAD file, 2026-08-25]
output/step/tank_cradle.step
205.6 x 162.6 x 47.0 mm

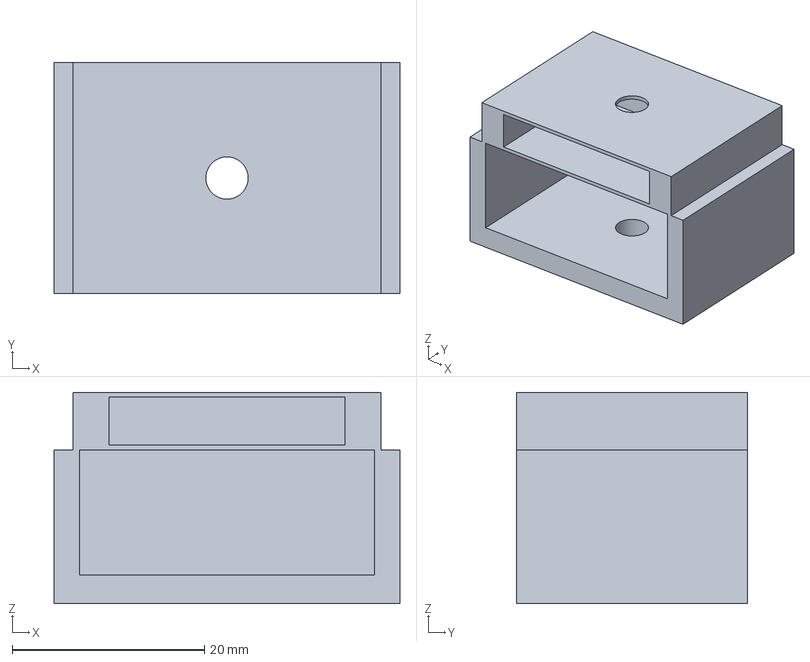
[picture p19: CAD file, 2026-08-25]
output/step/home-pro/led_clip_3030.step
36.0 x 24.0 x 22.0 mm

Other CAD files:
output/step/home-pro/tray_corner_2020.step
output/step/light_housing.step
output/step/electronics_box.step
output/step/home-pro/cable_clip_3030.step
output/step/electronics_lid.step
output/step/home-pro/camera_bracket_2020_30deg.step
output/step/home-pro/led_clip_2020.step
output/stl/camera_pod.stl
output/stl/electronics_box.stl
output/stl/electronics_lid.stl
output/stl/home-pro/cable_clip_2020.stl
output/stl/home-pro/cable_clip_3030.stl
output/stl/home-pro/camera_bracket_2020_30deg.stl
output/stl/home-pro/camera_bracket_3030_30deg.stl
output/stl/home-pro/led_clip_2020.stl
output/stl/home-pro/led_clip_3030.stl
output/stl/home-pro/sht40_sensor_guard.stl
output/stl/home-pro/tray_corner_2020.stl
output/stl/home-pro/tray_corner_3030.stl
output/stl/lid_left.stl
output/stl/lid_right.stl
output/stl/light_housing.stl
output/stl/mast_lower.stl
output/stl/mast_upper.stl
output/stl/tank_cradle.stl

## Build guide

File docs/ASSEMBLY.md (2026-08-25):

# SproutCam One 조립 설명서

## 필요한 공구

- 220 x 220 mm 이상 FDM 프린터
- 0.4 mm 노즐, PETG 필라멘트 약 700 g
- 인두, 납, 열수축튜브
- M4 육각렌치와 드라이버
- 디지털 캘리퍼스
- 멀티미터
- 누수받이와 키친타월

## 1. 용기부터 측정

PP 용기의 가장 넓은 외측 림을 측정합니다. 기본 모델은 180 x 120 mm입니다. 각 방향 실측치에 0.8 mm를 더해 `cad/generate_parts.py`의 `TANK_X`, `TANK_Y`에 입력합니다. 높이는 90-110 mm 범위가 적당합니다.

## 2. 출력

- 재료: PETG 권장. PLA는 조명 열과 슈도모나스 세척 과정에서 변형될 수 있습니다.
- 레이어: 0.20 mm
- 벽: 4줄
- 상하단: 5레이어
- 인필: 25% gyroid
- 서포트: 카메라 포드만 빌드플레이트 접촉형

`python cad/generate_parts.py` 실행 후 `output/stl`의 부품을 출력합니다.

## 3. 건식 조립

1. 탱크 크래들에 빈 PP 용기를 넣습니다.
2. 좌우 덮개를 M4x12 볼트로 결합합니다.
3. 하부 마스트를 크래들 뒤쪽 소켓에 M4x20으로 고정합니다.
4. 상부 마스트를 원하는 높이에서 볼트로 고정합니다.
5. LED 하우징을 상부 마스트에 고정합니다.
6. 카메라 포드를 LED 중앙 뒤쪽에 끼우고 렌즈가 두 포트의 중앙을 향하게 합니다.
7. 전자함은 탱크 최고 수위보다 최소 80 mm 높게 마스트 뒤에 장착합니다.

## 4. 배관

1. 펌프를 탱크 바닥에 흡착판으로 고정합니다.
2. 4x6 mm 튜브를 펌프에 연결하고 T 피팅으로 두 갈래로 나눕니다.
3. 각 튜브 끝을 네트팟 옆으로 향하게 합니다.
4. 튜브 끝은 물 밖 15 mm 위에서 아래를 향하게 해 역류를 줄입니다.
5. 플로트 스위치는 펌프 흡입구보다 20 mm 높은 지점에 둡니다.

## 5. 전기 조립

`WIRING.md`대로 배선하되 어댑터는 마지막에 연결합니다. 전원을 넣기 전에 멀티미터로 5V 레일이 4.85-5.15V인지 확인합니다. 카메라와 센서를 연결한 상태에서 벅 컨버터 전압을 조정하지 않습니다.

## 6. 24시간 누수 시험

1. 전자부품을 분리한 상태에서 탱크를 최대 수위까지 채웁니다.
2. 흰 키친타월 위에 올려 24시간 둡니다.
3. 용기, 펌프 전선 출구, 튜브 주변에 물기가 없어야 합니다.
4. 이후 펌프를 별도 USB 전원으로 10분씩 3회 작동시킵니다.
5. 한 번이라도 물기가 발견되면 전자부품을 설치하지 않습니다.

## 7. 첫 가동

1. 펌웨어의 Wi-Fi 이름과 비밀번호를 입력해 업로드합니다.
2. 시리얼 모니터에서 IP 주소를 확인합니다.
3. 같은 Wi-Fi의 휴대전화에서 해당 IP를 열어 대시보드에 접속합니다.
4. 펌프 3초 테스트 후 두 포트의 흐름을 확인합니다.
5. 물만 넣고 48시간 공회전한 다음 식물과 영양액을 넣습니다.

## 8. 사용

- 매일 같은 시간에 촬영하도록 설정합니다.
- 최초 2주는 수위를 매일 육안 확인합니다.
- 7일마다 탱크를 세척하고 영양액을 교체합니다.
- 뿌리가 펌프 흡입구에 닿기 전에 망을 설치합니다.

## 중단 조건

탄 냄새, 벅 컨버터 60도 이상, 전자함 내부 결로, 튜브 이탈, 탱크 균열, 펌프 소음의 급격한 증가 중 하나라도 발생하면 즉시 어댑터를 분리합니다.

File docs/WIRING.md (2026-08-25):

# 배선도

## 전원 구조

```text
KC 12V/3A 어댑터
        |
        +---- 2A 퓨즈 ---- MOSFET CH1 ---- 12V LED 바
        |
        +---- DC-DC 5V/3A ----+---- XIAO USB-C 또는 5V 입력
                               +---- MOSFET CH2 ---- 5V 펌프
```

모든 저전압 GND는 공통으로 연결합니다. 12V 양극과 5V 양극을 서로 직접 연결하면 안 됩니다.

## XIAO 핀 배정

| XIAO 핀 | 연결 | 비고 |
|---|---|---|
| D0 | 플로트 스위치 | `INPUT_PULLUP`, 다른 쪽은 GND |
| D1 | 펌프 MOSFET 신호 | 3.3V 로직 호환 모듈만 사용 |
| D2 | LED MOSFET 신호 | PWM 가능 |
| D4/SDA | SHT40 SDA | I2C |
| D5/SCL | SHT40 SCL | I2C |
| 3V3 | 센서 VCC | 펌프 연결 금지 |
| GND | 센서/MOSFET 공통 GND | 스타 접지 권장 |

카메라는 Sense 확장보드에 이미 연결되어 있으므로 별도 배선하지 않습니다.

## 안전 규칙

- 펌프를 ESP32 GPIO에 직접 연결하지 않습니다.
- 펌프가 브러시 모터라면 MOSFET 모듈의 플라이백 다이오드 유무를 확인합니다.
- 전자함으로 들어오는 케이블은 아래로 한 번 처지게 해 물방울 고리(drip loop)를 만듭니다.
- 플로트 스위치가 LOW WATER를 감지하면 자동 펌프를 금지합니다.
- 펌프 한 번의 최대 작동은 30초, 하루 누적은 5분으로 제한합니다.

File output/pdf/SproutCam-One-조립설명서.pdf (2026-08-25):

SPROUTCAM ONE / BUILD KIT v0.1

# SPROUTCAM ONE

## 카메라 성장 기록형 2포트 수경재배기

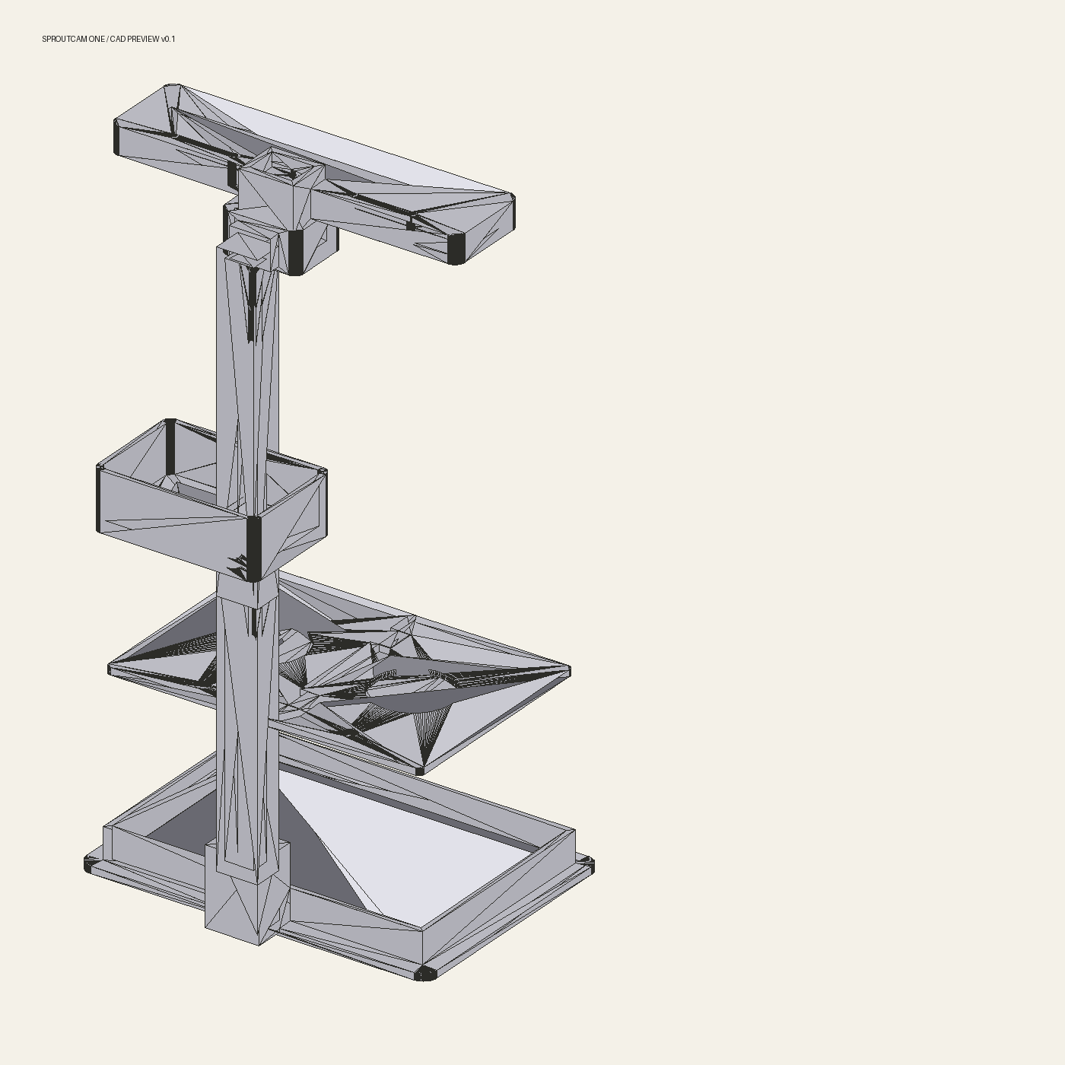
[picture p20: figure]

직접 제작용 개발 시제품 - 외장 12V 어댑터, 시판 PP 물탱크, 3D 프린팅 프레임을 사용합니다.

# 1. 제품 개요

항목 | 기본 설계
재배 포트 | 50 mm 네트팟 2개
물탱크 | 외경 180 x 120 x 90-110 mm PP 용기
본체 크기 | 약 220 x 155 x 385 mm
카메라 | XIAO ESP32-S3 Sense / OV3660 또는 호환
전원 | KC 인증 12V 3A 외장 어댑터
제어 | 로컬 Wi-Fi 대시보드, 사진, 펌프, 조명
권장 작물 | 바질, 루꼴라, 상추, 청경채

## 설계 원칙

물과 전자를 분리하기 위해 물탱크는 출력하지 않고 식품용 PP 용기를 사용합니다. 전자함은 최고 수위보다 80 mm 이상 높게 장착하며, 본체 내부에는 220 V가 들어가지 않습니다.

카메라 AI는 성장 기록과 상태 추정을 담당합니다. 펌프 안전은 수위 스위치와 30초 하드 타임아웃이 담당하므로 영상 판단이 실패해도 계속 급수되지 않습니다.

## 예상 부품비

필수 부품 약 11만-14만 원 + PETG 약 2만 원. 공구, 배송비, 3D 출력 대행비는 제외한 1대 개발 비용입니다.

# 2. 구매 목록

부품 | 규격 | 수량 | 예상가
XIAO ESP32-S3 Sense | 프리솔더 권장 | 1 | 25,520
SHT40 | I2C 3.3V | 1 | 9,000
수직 플로트 스위치 | PP, NO/NC | 1 | 4,000
미니 수중펌프 | 5V, 80-120 L/h | 1 | 7,000
MOSFET 모듈 | 2채널, 3.3V 로직 | 1 | 7,000
식물 LED 바 | 12V, 10-15W, 180-200mm | 1 | 18,000
KC 어댑터 | 12V 3A, 5.5x2.1 | 1 | 15,000
DC-DC 벅 | 12V -> 5V 3A | 1 | 5,000
실리콘 튜브 | 내경 4 / 외경 6mm | 2m | 5,000
네트팟 | 상단 외경 50mm | 2 | 3,000
PP 식품용기 | 180 x 120 x 90-110mm | 1 | 6,000
볼트/배선/커넥터 | M4, JST, 열수축튜브 | 1식 | 13,000

정확한 구매 링크는 저장소의 docs/BOM.csv에 있습니다. LED 바의 실제 단면이 190 x 32 x 8 mm를 넘으면 하우징 CAD 치수를 수정하십시오.

# 3. 출력 부품

파일 | 최대 크기 mm | 역할
tank_cradle | 205.6 x 162.6 x 47 | 탱크 받침과 하부 마스트 소켓
lid_left / right | 101.5 x 128 x 4 | 분할 탱크 덮개와 네트팟 홀
mast_lower | 24 x 18 x 205 | 하부 마스트와 결합 텅
mast_upper | 24 x 18 x 190 | 높이 조절 상부 마스트
light_housing | 205 x 66.5 x 28 | LED 바 하우징
camera_pod | 46 x 45 x 24 | 카메라 및 USB-C 접근
electronics_box | 96 x 64 x 34 | MOSFET, 벅, 배선 수납
electronics_lid | 96 x 64 x 5.7 | 전자함 압입식 덮개

## 슬라이서 설정

PETG / 0.20 mm 레이어 / 벽 4줄 / 상하단 5레이어 / 25% gyroid. 카메라 포드 외에는 기본적으로 서포트가 필요하지 않습니다. 처음에는 lid_left 한 장만 출력해 네트팟과 용기 치수를 확인하십시오.

CAD 기준 치수는 0.8 mm 조립 여유를 포함합니다. 프린터 수축률이 큰 경우 TANK_CLEARANCE를 1.2 mm까지 늘립니다.

# 4. 조립 순서

01 빈 탱크를 크래들에 넣고 흔들림과 0.5-1.5 mm 간격을 확인합니다.

02 분할 덮개를 M4x12 볼트로 결합하고 50 mm 네트팟 두 개를 끼웁니다.

03 하부와 상부 마스트를 체결하고 LED-식물 간격을 200-300 mm로 맞춥니다.

04 LED 하우징과 카메라 포드를 설치해 렌즈가 두 포트 중앙을 향하게 합니다.

05 펌프와 4x6 mm 튜브를 설치하고 플로트 스위치를 흡입구보다 20 mm 높게 둡니다.

06 전자함을 최고 수위보다 80 mm 이상 높게 고정하고 모든 케이블에 물방울 고리를 만듭니다.

07 전자부품을 빼고 24시간 누수 시험 후 펌프를 10분씩 세 차례 공회전합니다.

08 5V 레일을 측정한 뒤 펌웨어를 올리고 대시보드에서 펌프 3초 시험을 합니다.

# 5. 배선 및 최초 가동

12V 입력은 2A 퓨즈를 거쳐 LED MOSFET으로 연결합니다. 같은 입력에서 DC-DC 벅으로 5V를 만들고 XIAO와 펌프 MOSFET에 공급합니다.

핀 | 연결 | 주의
D0 | 플로트 스위치 | INPUT_PULLUP, 반대쪽 GND
D1 | 펌프 MOSFET | 펌프 직접 연결 금지
D2 | LED MOSFET | 3.3V 로직 호환
D4 / D5 | SHT40 SDA / SCL | 3.3V I2C
3V3 | 센서 전원 | 모터 연결 금지
GND | 공통 접지 | 12V/5V 음극 공통

## 최초 가동 체크

□ 5V 레일이 4.85-5.15V이다.
□ 저수위에서 펌프 명령이 거부된다.
□ 펌프 3초 명령 후 자동으로 정지한다.
□ 전자함과 커넥터에 물방울이 없다.
□ 카메라 화면에 두 재배 포트가 모두 보인다.
□ LED 하우징을 30분 켠 뒤 손으로 만질 수 있는 온도다.

즉시 전원 분리: 탄 냄새, 60°C 이상의 벅 컨버터, 전자함 결로, 탱크 균열, 튜브 이탈, 펌프 소음 급증.

이 문서는 개인 제작용 개발 안내입니다. 완제품 판매 전에는 전파·전기 안전, 재료 안전성, 누수 및 장기 내구성 시험이 별도로 필요합니다.

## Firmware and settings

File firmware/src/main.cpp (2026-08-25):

#include <Arduino.h>
#include <WiFi.h>
#include <WebServer.h>
#include <Wire.h>
#include "esp_camera.h"
#include "camera_pins.h"
#include "secrets.h"

constexpr uint8_t PIN_LOW_WATER = D0;
constexpr uint8_t PIN_PUMP = D1;
constexpr uint8_t PIN_LIGHT = D2;
constexpr unsigned long PUMP_MAX_RUN_MS = 30000;
constexpr unsigned long PUMP_DAILY_LIMIT_MS = 300000;
constexpr unsigned long DAY_MS = 86400000;

WebServer server(80);
unsigned long pumpStartedAt = 0;
unsigned long pumpRequestedMs = 0;
unsigned long pumpUsedToday = 0;
unsigned long dayStartedAt = 0;
bool pumpRunning = false;
bool sensorReady = false;

bool readSHT40(float &temperature, float &humidity) {
  Wire.beginTransmission(0x44); Wire.write(0xFD);
  if (Wire.endTransmission() != 0) return false;
  delay(10);
  if (Wire.requestFrom(0x44, 6) != 6) return false;
  uint16_t rawT=(Wire.read()<<8)|Wire.read(); Wire.read();
  uint16_t rawH=(Wire.read()<<8)|Wire.read(); Wire.read();
  temperature=-45.0f+175.0f*(rawT/65535.0f);
  humidity=-6.0f+125.0f*(rawH/65535.0f);
  humidity=constrain(humidity,0.0f,100.0f);
  return true;
}

const char DASHBOARD[] PROGMEM = R"HTML(
<!doctype html><html lang="ko"><meta name="viewport" content="width=device-width,initial-scale=1">
<style>body{font-family:system-ui;background:#f3f2ea;color:#111;margin:0}.wrap{max-width:520px;margin:auto;padding:24px}h1{font-size:38px;margin:12px 0}.card{background:white;border:1px solid #111;border-radius:18px;padding:18px;margin:14px 0;box-shadow:5px 5px #111}img{width:100%;border-radius:12px;background:#ddd}button{background:#b7ff22;border:1px solid #111;border-radius:999px;padding:13px 18px;font-weight:800;margin-right:8px}.danger{background:#ff6138}.muted{color:#666;font-size:13px}</style>
<div class="wrap"><div class="muted">SPROUTCAM ONE / LOCAL</div><h1>오늘도 자라는 중.</h1>
<div class="card"><img id="photo" src="/photo.jpg"><p><button onclick="snap()">새로 촬영</button></p></div>
<div class="card"><h2>환경</h2><div id="status">읽는 중...</div></div>
<div class="card"><h2>수동 제어</h2><button onclick="pump(3)">펌프 3초</button><button class="danger" onclick="pump(0)">정지</button><p class="muted">저수위에서는 펌프가 켜지지 않습니다.</p></div></div>
<script>
async function refresh(){let r=await fetch('/api/status');let s=await r.json();status.innerHTML=`온도 <b>${s.temperature_c}°C</b><br>습도 <b>${s.humidity_pct}%</b><br>수위 <b>${s.low_water?'부족':'정상'}</b><br>펌프 <b>${s.pump?'작동':'정지'}</b>`}
function snap(){photo.src='/photo.jpg?t='+Date.now()}
async function pump(sec){await fetch('/api/pump?seconds='+sec,{method:'POST'});refresh()}
refresh();setInterval(refresh,5000);
</script></html>)HTML";

bool lowWater() { return digitalRead(PIN_LOW_WATER) == HIGH; }

void stopPump() {
  if (pumpRunning) {
    unsigned long elapsed = millis() - pumpStartedAt;
    pumpUsedToday += min(elapsed, PUMP_MAX_RUN_MS);
  }
  digitalWrite(PIN_PUMP, LOW);
  pumpRunning = false;
}

bool startPump(unsigned long durationMs) {
  if (lowWater() || pumpRunning || pumpUsedToday >= PUMP_DAILY_LIMIT_MS) return false;
  durationMs = min(durationMs, PUMP_MAX_RUN_MS);
  pumpStartedAt = millis();
  pumpRequestedMs = durationMs;
  pumpRunning = true;
  digitalWrite(PIN_PUMP, HIGH);
  return true;
}

void initCamera() {
  camera_config_t c{};
  c.ledc_channel = LEDC_CHANNEL_0; c.ledc_timer = LEDC_TIMER_0;
  c.pin_d0=Y2_GPIO_NUM; c.pin_d1=Y3_GPIO_NUM; c.pin_d2=Y4_GPIO_NUM; c.pin_d3=Y5_GPIO_NUM;
  c.pin_d4=Y6_GPIO_NUM; c.pin_d5=Y7_GPIO_NUM; c.pin_d6=Y8_GPIO_NUM; c.pin_d7=Y9_GPIO_NUM;
  c.pin_xclk=XCLK_GPIO_NUM; c.pin_pclk=PCLK_GPIO_NUM; c.pin_vsync=VSYNC_GPIO_NUM;
  c.pin_href=HREF_GPIO_NUM; c.pin_sccb_sda=SIOD_GPIO_NUM; c.pin_sccb_scl=SIOC_GPIO_NUM;
  c.pin_pwdn=PWDN_GPIO_NUM; c.pin_reset=RESET_GPIO_NUM; c.xclk_freq_hz=20000000;
  c.pixel_format=PIXFORMAT_JPEG; c.frame_size=FRAMESIZE_SXGA; c.jpeg_quality=12; c.fb_count=2;
  c.grab_mode=CAMERA_GRAB_LATEST; c.fb_location=CAMERA_FB_IN_PSRAM;
  if (esp_camera_init(&c) != ESP_OK) Serial.println("camera init failed");
}

void handleStatus() {
  float temperature = NAN, humidity = NAN;
  sensorReady=readSHT40(temperature,humidity);
  String json = "{\"temperature_c\":" + String(temperature,1) +
    ",\"humidity_pct\":" + String(humidity,1) +
    ",\"low_water\":" + String(lowWater()?"true":"false") +
    ",\"pump\":" + String(pumpRunning?"true":"false") +
    ",\"pump_daily_ms\":" + String(pumpUsedToday) + "}";
  server.send(200,"application/json",json);
}

void handlePhoto() {
  camera_fb_t *fb = esp_camera_fb_get();
  if (!fb) { server.send(503,"text/plain","camera unavailable"); return; }
  server.setContentLength(fb->len);
  server.send(200,"image/jpeg","");
  WiFiClient client=server.client(); client.write(fb->buf,fb->len);
  esp_camera_fb_return(fb);
}

void handlePump() {
  int seconds = constrain(server.arg("seconds").toInt(),0,30);
  if (seconds == 0) { stopPump(); server.send(200,"application/json","{\"ok\":true}"); return; }
  bool ok=startPump(seconds*1000UL);
  server.send(ok?200:409,"application/json",ok?"{\"ok\":true}":"{\"ok\":false,\"reason\":\"low-water-or-limit\"}");
}

void setup() {
  Serial.begin(115200);
  pinMode(PIN_LOW_WATER,INPUT_PULLUP); pinMode(PIN_PUMP,OUTPUT); pinMode(PIN_LIGHT,OUTPUT);
  stopPump(); digitalWrite(PIN_LIGHT,HIGH);
  Wire.begin(); initCamera();
  WiFi.begin(WIFI_SSID,WIFI_PASSWORD);
  for (int i=0;i<60 && WiFi.status()!=WL_CONNECTED;i++){delay(500);Serial.print('.');}
  Serial.printf("\nDashboard: http://%s/\n",WiFi.localIP().toString().c_str());
  server.on("/",[](){server.send_P(200,"text/html",DASHBOARD);});
  server.on("/api/status",HTTP_GET,handleStatus);
  server.on("/photo.jpg",HTTP_GET,handlePhoto);
  server.on("/api/pump",HTTP_POST,handlePump);
  server.begin(); dayStartedAt=millis();
}

void loop() {
  server.handleClient();
  unsigned long now=millis();
  if (pumpRunning && (lowWater() || now-pumpStartedAt>=pumpRequestedMs)) stopPump();
  if (now-dayStartedAt>=DAY_MS){pumpUsedToday=0;dayStartedAt=now;}
  delay(2);
}

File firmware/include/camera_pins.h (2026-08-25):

#pragma once

// Official XIAO ESP32-S3 Sense camera mapping.
#define PWDN_GPIO_NUM  -1
#define RESET_GPIO_NUM -1
#define XCLK_GPIO_NUM  10
#define SIOD_GPIO_NUM  40
#define SIOC_GPIO_NUM  39
#define Y9_GPIO_NUM    48
#define Y8_GPIO_NUM    11
#define Y7_GPIO_NUM    12
#define Y6_GPIO_NUM    14
#define Y5_GPIO_NUM    16
#define Y4_GPIO_NUM    18
#define Y3_GPIO_NUM    17
#define Y2_GPIO_NUM    15
#define VSYNC_GPIO_NUM 38
#define HREF_GPIO_NUM  47
#define PCLK_GPIO_NUM  13

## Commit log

2026-08-25 Create SproutCam One printable prototype kit
    [BOM.csv, camera_pod.step, camera_pod.stl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]
2026-08-25 Add HOME 12 and PRO 48 fabrication package
    [HOME12_BOM.csv, HOME_PRO_CUTLIST.csv, PRO48_BOM.csv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]
